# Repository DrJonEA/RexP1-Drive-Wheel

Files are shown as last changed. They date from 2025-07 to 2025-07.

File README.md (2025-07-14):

# RexP1-Drive-Wheel

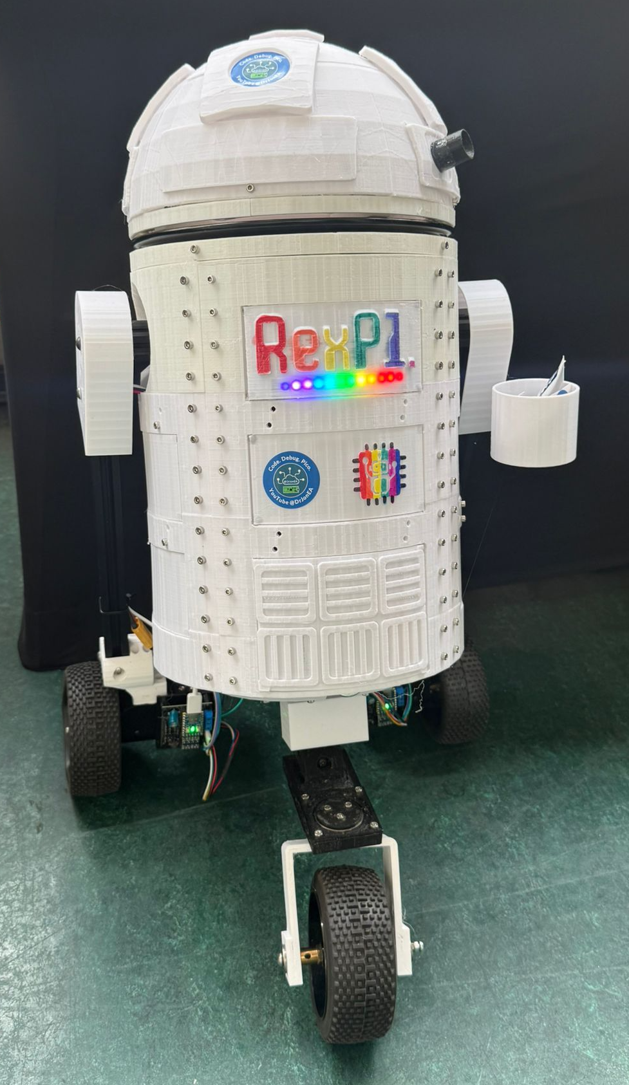
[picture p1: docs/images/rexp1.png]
isolated

Drive wheel for my RexP1 Astro Droid Project based on a RP2040Zero board. This Repo repreents the drive wheel subsystem for RexP1.

Checkout the [videos guides](https://www.youtube.com/playlist?list=PLspDyukWAtRUPNdlktaOdk7os9TfTEFh1) to the project over on my [YouTube Channel DrJonEA](https://youtube.com/@drjonea).
 
## RexP1 Intro
RexP1 is a reimagined Star War's inspired Astro Droid based on the R series Droids. It is based on Raspberry PI 5, RP2040 and RP2350 boards. It's control system is a distributed net based on ROS2 and MicroROS frameworks.

All my work on RexP1 is available to  my sponsors. That includes not just this submodule but all the submodules, the build instructions, PCB designs, STL files, CAD designs and most important acess to me to ask questions. Take a look at the sponsorship button on the github repo.

## The Repo
This repo includes the PCB design for the drive wheels and assoicated documentation. It also includes the firmware for a RP2040Zero which acts as a ROS2 Node to control the Wheel and some other sensors.

## Libraries
Note libraries have not been included as submodules in this repo. That is because I wanted just a single copy of the libraries in the master repo for RexP1. So take note of the [lib documentation](docs/Libraries.md).

## Build process
The firmware should build like most *complex* Pico SDK firmware projects. Normal procedure:
```
mkdir build
cd build
cmake ..
make
```
If you have ninja use that instead of make for Windows. Just make sure you update the CMakelists.txt to point to your libraries and that the environment variable PICO_SDK_PATH is defined to point to the SDK.

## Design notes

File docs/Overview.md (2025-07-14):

# Project Overview: 
RexP1 Droid with Wheel-Specific RP2040 PCBs —an imaginative reinterpretation of an astro droid—combines modular wheel control with microROS-powered motor coordination. Using RP2040 Zero boards positioned close to each wheel, the design dramatically reduces wiring complexity and enables each module to relay precise rotational data and drive control back to a central Raspberry Pi 5.

# Core Architecture
MicroROS Integration: Each RP2040 runs microROS for real-time motor control and feedback.

Modular Boards: Custom 43×43 mm PCBs (fabricated by PCBWay) for each wheel contain sensors, controllers, and communication interfaces.

## Motor System:

Geared 37D motors with 131:1 ratio deliver 83 RPM at 12V, ideal for slow, deliberate movement (~0.6 m/s).

Encoders with hall-effect sensors provide 2096 ticks per rotation, enabling detailed speed and position tracking.

L298N motor drivers selected for familiarity and consistency across droid designs.

##️ Peripheral & Expansion Capabilities

### Sensor Suite:

Ultrasonic Sensors (HC-SR04): Mounted around rear wheels to mitigate lidar blind spots, particularly in reflective or low-contrast environments.

WS2812B LED Strips: Planned for visual effects and thematic flair, likely mounted vertically alongside the wheels.

I²C Connector: Included for future sensor or device expansions.

Lighting Control: Separate motor controller channels drive bright 12V headlights and taillights for enhanced immersion and potential navigation utility.

Level Shifters: Used to manage 5V logic levels from ultrasonic sensors and WS2812B LEDs.

#️ Board Design Insights
Created in KiCad using modular schematic sections connected via net labels—allowing flexible GPIO reassignment and efficient trace routing.

Consistent mechanical layout across all boards for streamlined mechanical integration and enclosure design.

# Software Strategy
PWM Motor Control: Managed locally on RP2040; algorithms fine-tuned to reflect encoder feedback.

ROS2 Communication: Central Raspberry Pi 5 handles high-level control via twist messages, converting them to joint jog/state ROS messages.

Motion Testing: Remote control mode currently in use to validate board responsiveness and individual wheel behavior.

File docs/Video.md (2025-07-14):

# Video Guides

[This video](https://youtu.be/suo1PoJ09U0) talks about the PCB design for the Motor Controllers.

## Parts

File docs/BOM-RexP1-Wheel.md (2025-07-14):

# Bill of Materials

This is a BOM for the controller PCB. Headerpins will also be needed for some of the connectors.

|Reference |Footprint	 |	Qty	| Link | Notes
|---|---|----|---|---|
|ADT1	|Conn_01x04_Socket|	1 |https://amzn.to/469HaiG | This is really a generic I2C connection |	
|B1	|SPARKFUN_LOGIC_LEVEL_CONVERTER|1 |https://amzn.to/4nIsf5v|	
|C1|	470uF|	1| ||	
|HCSR04-1,HCSR04-2,HCSR04-3| Conn_01x04_Pin| 3 | https://amzn.to/44LDqRY| Header for Ultrasound distance sensors|
|L298N1| Conn_01x04_Pin | 1 | https://amzn.to/4nMWF6s||
|WS2812B-1,WS2812B-2|	Conn_01x04_Pin| 2| https://amzn.to/4nMWF6s| Header for WS2812B LEDs if required|
|J2|	Screw_Terminal_01x03| 1 |	https://amzn.to/4nMWF6s||
|J3|	PinHeader_1x03_P2.54mm_Vertical|1|| Uart0 Connector|	
|Motor1|	Conn_01x06_Pin| 1|https://amzn.to/3U7HU0u| Motor used 132:1 grear ratio|
|R1|	220R| Resistor_THT| 1 |||
|RZ1	|RP2040-Zero| 1|https://amzn.to/3IHgJHf||
|SW1|	SW_PUSH_6mm_H8.5mm |1|https://amzn.to/3TEUpAC||	
|U1,U2,U3|	HC-SR04| 3|https://amzn.to/44LDqRY||

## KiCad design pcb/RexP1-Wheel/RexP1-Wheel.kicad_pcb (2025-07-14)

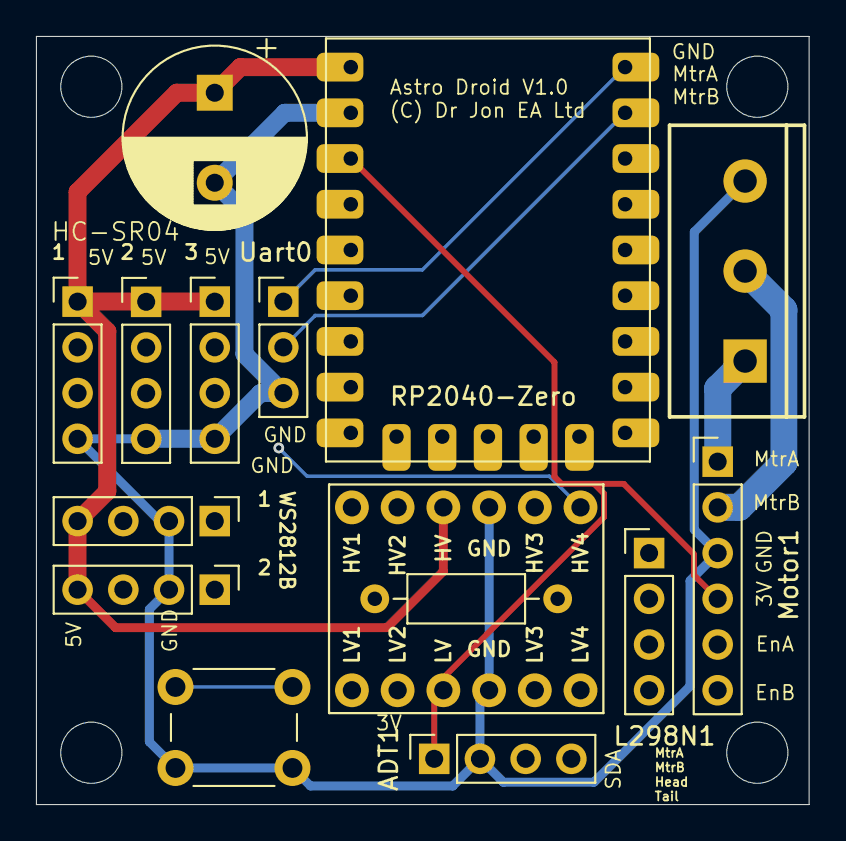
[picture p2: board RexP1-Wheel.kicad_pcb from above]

Board: 4 copper layers, 42.9 x 42.7 mm, 15 parts (0 on the bottom side), 29 nets.

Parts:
ADT1: Conn_01x04_Socket; PinSocket_1x04_P2.54mm_Vertical
B1: SPARKFUN_LOGIC_LEVEL_CONVERTER
C1: 470uF; CP_Radial_D10.0mm_P5.00mm
HCSR04-1, HCSR04-2, HCSR04-3: Conn_01x04_Pin; PinHeader_1x04_P2.54mm_Vertical
J2: Screw_Terminal_01x03; SCREWTERMINAL-5MM-3
J3: Uart0; PinHeader_1x03_P2.54mm_Vertical
L298N1: Conn_01x04_Pin; PinHeader_1x04_P2.54mm_Vertical
Motor1: Conn_01x06_Pin; PinHeader_1x06_P2.54mm_Vertical
R1: 220R; R_Axial_DIN0207_L6.3mm_D2.5mm_P10.16mm_Horizontal
RZ1: RP2040-Zero
SW1: SW_SPST; SW_PUSH_6mm_H8.5mm
WS2812B-1, WS2812B-2: Conn_01x04_Pin; PinHeader_1x04_P2.54mm_Vertical

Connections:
+3V3: ADT1.1 (VCC), B1.LV, Motor1.4 (VCC), RZ1.30 (3V3)
+5V: B1.HV, C1.1, HCSR04-1.1 (VCC), HCSR04-2.1 (VCC), HCSR04-3.1 (VCC), RZ1.32 (5V), WS2812B-1.4 (VDD), WS2812B-2.4 (VDD)
/Echo-1: B1.LV2 (LV_RXO_1), RZ1.12 (GP12)
/Echo-2: B1.LV3 (LV_RXO_2), RZ1.11 (GP11)
/Echo-3: B1.LV4 (LV_TXI_2), RZ1.10 (GP10)
/Echo-HV-1: B1.HV2 (HV_RXI_1), HCSR04-1.3 (Echo)
/Echo-HV-2: B1.HV3 (HV_RXI_2), HCSR04-2.3 (Echo)
/Echo-HV-3: B1.HV4 (HV_TXO_2), HCSR04-3.3 (Echo)
/EncA: Motor1.5 (EncoderA), RZ1.5 (GP5)
/EncB: Motor1.6 (EncoderB), RZ1.4 (GP4)
/Headlight: L298N1.3 (IN3), RZ1.7 (GP7)
/MtrA: L298N1.1 (IN1), RZ1.3 (GP3)
/MtrB: L298N1.2 (IN2), RZ1.2 (GP2)
/SCL: ADT1.3 (SCL), RZ1.9 (GP9)
/SDA: ADT1.4 (SDA), RZ1.8 (GP8)
/Taillight: L298N1.4 (IN4), RZ1.6 (GP6)
/Trigger-1: HCSR04-1.2 (Trig), RZ1.27 (GP27)
/Trigger-2: HCSR04-2.2 (Trig), RZ1.26 (GP26)
/Trigger-3: HCSR04-3.2 (Trig), RZ1.15 (GP15)
/WS2812B: B1.LV1 (LV_TXI_1), RZ1.13 (GP13)
/sw: RZ1.14 (GP14), SW1.2 (B)
GND: ADT1.2 (GND), B1.GND1 (GND), B1.GND2 (GND), C1.2, HCSR04-1.4 (GND), HCSR04-2.4 (GND), HCSR04-3.4 (GND), J2.3 (GND), J3.3 (GND), Motor1.3 (GND), RZ1.31 (GND), SW1.1 (A), WS2812B-1.2 (Gnd), WS2812B-2.2 (Gnd)
unnamed: B1.HV1 (HV_TXO_1), R1.1
unnamed: J2.2 (MtrPwrB), Motor1.2 (Mtr_PwrB)
unnamed: J2.1 (Mtr_PwrA), Motor1.1 (Mtr_PwrA)
unnamed: J3.2 (RX), RZ1.1 (GP1)
unnamed: J3.1 (TX), RZ1.0 (GP0)
unnamed: R1.2, WS2812B-1.3 (In)
unnamed: WS2812B-1.1 (Out), WS2812B-2.3 (In)

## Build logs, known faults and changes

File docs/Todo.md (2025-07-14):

# Todo List

<ol>
<li>WS2812B LED Not implimented</li>
<li>Ultrasound sensors untested</li>
</ol>

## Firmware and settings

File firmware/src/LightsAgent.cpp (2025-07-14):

/*
 * LightsAgent.cpp
 *
 *  Created on: 22 Mar 2025
 *      Author: jondurrant
 */

#include "LightsAgent.h"
#include "ConfigEntity.h"
#include "AstroDroidConfig.h"
#include "tiny-json.h"
#include "NVSJson.h"

#include "pico/stdlib.h"
#include "hardware/pwm.h"

 const char * LightsAgent::X_TOPIC_LEFT= "/Astro/lightsLEFT";
 const char * LightsAgent::X_TOPIC_RIGHT = "/Astro/lightsRIGHT";

LightsAgent::LightsAgent() {
	initMsg();

	gpio_init(HEADLIGHT);
	gpio_set_function(HEADLIGHT, GPIO_FUNC_PWM);
	pwm_set_gpio_level(HEADLIGHT, 0);
	uint slice_num = pwm_gpio_to_slice_num(HEADLIGHT);
	pwm_set_enabled(slice_num, true);

	gpio_init(TAILLIGHT);
	gpio_set_function(TAILLIGHT, GPIO_FUNC_PWM);
	pwm_set_gpio_level(TAILLIGHT, 0);
	slice_num = pwm_gpio_to_slice_num(TAILLIGHT);
	pwm_set_enabled(slice_num, true);
}

LightsAgent::~LightsAgent() {
	// TODO Auto-generated destructor stub
}

/***
 * Create the publishing entities
 * @param node
 * @param support
 */
void LightsAgent::createEntities(rcl_node_t *node, rclc_support_t *support){
	rcl_ret_t res;

	NVSJson * nvs = NVSJson::getInstance();

	bool left;
	const char *topic = NULL;
	nvs->get_bool(CONFIG_LEFT,  &left);
	if (left){
		topic = LightsAgent::X_TOPIC_LEFT;
	} else {
		topic = LightsAgent::X_TOPIC_RIGHT;
	}
	res = rclc_subscription_init_default(
			  &xSubLights,
			  node,
			 ROSIDL_GET_MSG_TYPE_SUPPORT(std_msgs, msg, String),
			  topic
			  );

	if (res != RCL_RET_OK){
		printf("ERROR: LightsAgent::createEntities failed to init subscriber \n");
	}

}

/***
 * Destroy the publishing entities
 * @param node
 * @param support
 */
void LightsAgent::destroyEntities(rcl_node_t *node, rclc_support_t *support){
	rcl_subscription_fini(&xSubLights, 	node);
}


/***
 * Provide a count of the number of entities
 * @return number of entities >=0
 */
uint LightsAgent::getCount(){
	return 1;
}

/***
 * Return the number of handles needed by the executor
 * @return
 */
uint LightsAgent::getHandles(){
	uint res = 1;
	return res;
}

/***
 * Add subscribers, guards and timers to the executor
 * @param executor
 */
void LightsAgent::addToExecutor(rclc_executor_t *executor){

	buildContext(&xSubLightsContext, NULL);
	rcl_ret_t res = rclc_executor_add_subscription_with_context(
			executor,
			&xSubLights,
			&xLightsMsg,
			uRosEntities::subscriptionCallback,
			&xSubLightsContext,
			ON_NEW_DATA);

	if (res != RCL_RET_OK){
		printf("ERROR: ConfigEntity::addToExecutor failed to add executor \n");
	}
}

/***
 * Handle subscription msg
 * @param msg
 * @param localContext
 */
void LightsAgent::handleSubscriptionMsg(
		const void* msg,
		uRosSubContext_t* context){

	printf("LightsAgent::handleSubscriptionMsg\n");

	if (context == &xSubLightsContext){
		std_msgs__msg__String * pStringMsg = (std_msgs__msg__String *) msg;

		json_t mem[LIGHTS_AGENT_MAX_KEYS];
		json_t const* json = json_create( pStringMsg->data.data, mem, sizeof mem / sizeof *mem );
		if ( !json ) {
			printf("Error json create.\n");
			return ;
		}
		json_t const *cmd ;

		//Headlights
		cmd = json_getProperty(json, LIGHTS_AGENT_HEADLIGHT);
		if (cmd != NULL){
			if (json_getType(cmd) == JSON_REAL){
				double head = json_getReal(cmd);
				setHeadlights(head);
			}
		}

		//Taillights
		cmd = json_getProperty(json, LIGHTS_AGENT_TAILLIGHT);
		if (cmd != NULL){
			if (json_getType(cmd) == JSON_REAL){
				double tail = json_getReal(cmd);
				setTaillights(tail);
			}
		}

		//Colour
		cmd = json_getProperty(json, LIGHTS_AGENT_COLOUR);
		if (cmd != NULL){
			if (json_getType(cmd) == JSON_TEXT){
				const char *s = json_getValue(cmd);
				setColour(s);
			}
		}

		//Pattern
		cmd = json_getProperty(json, LIGHTS_AGENT_PATTERN);
		if (cmd != NULL){
			if (json_getType(cmd) == JSON_INTEGER){
				int p = json_getInteger(cmd);
				setPattern(p);
			}
		}



	}
}

void LightsAgent::initMsg(){
	xLightsMsg.data.data = xBuffer;
	xLightsMsg.data.capacity = LIGHTS_AGENT_BUFFER_SIZE;
}

void LightsAgent::setHeadlights(double head){
	uint16_t level;
	if (head >= 1.0){
		level = 0xffff;
	} else {
		double f = head * 255.0;
		level = (int)f;
		level = level * level;
	}
	pwm_set_gpio_level(HEADLIGHT, level);
}

void LightsAgent::setTaillights(double tail){
	uint16_t level;
	if (tail >= 1.0){
		level = 0xffff;
	} else {
		double f = tail * 255.0;
		level = (int)f;
		level = level * level;
	}
	pwm_set_gpio_level(TAILLIGHT, level);
}

void LightsAgent::setColour(const char *hexString){

}

void LightsAgent::setPattern(int p){

}
